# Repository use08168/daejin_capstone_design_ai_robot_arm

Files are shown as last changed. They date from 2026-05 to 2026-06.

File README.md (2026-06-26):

# 🦾 AI 기반 6-DOF 음성 제어 로봇팔

> **Voice-Controlled Autonomous Grasping Manipulator**
> 대진대학교 캡스톤 디자인 — 한국어 음성 명령으로 객체를 인식하고 안전하게 그립하는 분산 AI 추론 기반 6-DOF 로봇팔.

<p align="center">
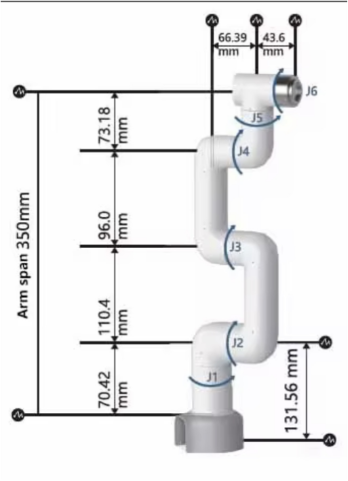
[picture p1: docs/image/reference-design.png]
6-DOF 로봇팔 설계 (J1~J6, arm span 350mm)
  
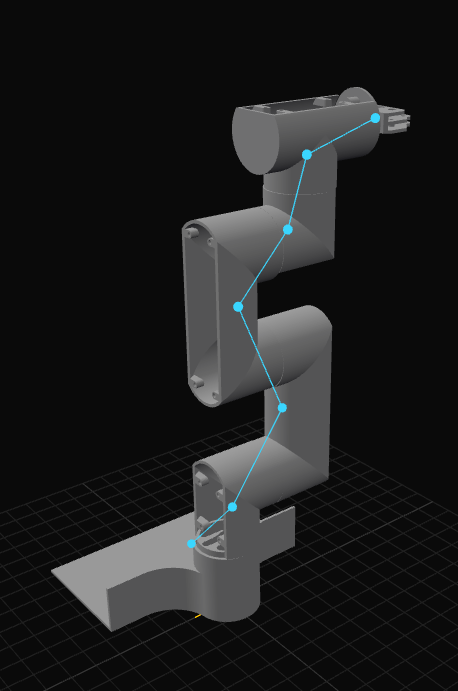
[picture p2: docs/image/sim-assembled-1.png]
STL로 조립한 3D 디지털 트윈 (6관절 리깅)
  
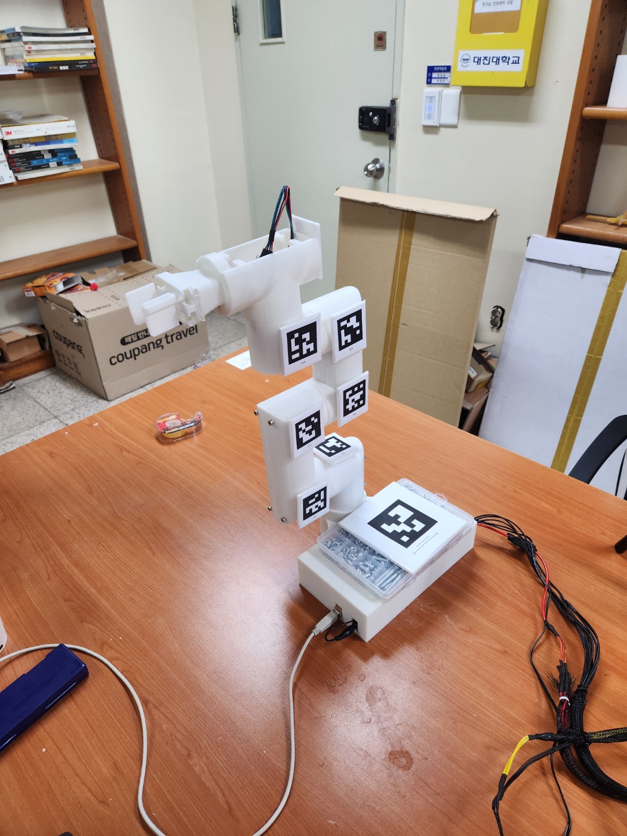
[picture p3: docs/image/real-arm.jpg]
실물 6-DOF 로봇팔 (각 링크에 ArUco 마커 부착)
  
</p>
<p align="center"><sub>참조 설계(좌) → 실측 STL로 만든 3D 디지털 트윈(중) → 실물 6-DOF 로봇팔(우, 각 링크에 ArUco 마커). 시뮬레이션으로 동작을 미리 보고 실물과 연동 구동.</sub></p>

```
사용자: "빨간 컵을 책 옆에 놔줘"
   ↓
음성 인식 → 객체 인식 → 의도 파악 → 동작 계획 →
IK 계산 → 안전 검증 → 모터 제어 → 그립 → 이동 → 놓기
```

---

## 🎬 데모 영상

> Google Drive(뷰어 공개) 링크. 각 항목은 해당 기술 문서에도 연결돼 있다.

| 데모 | 영상 |
|---|---|
| **3D 시뮬레이터 동작** (조립·리깅·제어) | [▶ 보기](https://drive.google.com/file/d/1hU2PR68-Gy2XqOHGjDWO9H2JxIDRQaFw/view?usp=sharing) |
| **잡기·놓기 런타임** (AI 파지 → 들기 → 놓기) | [▶ ①](https://drive.google.com/file/d/1SrEo43e4rWohGsKSrXign7xtEpKEwyvU/view?usp=sharing) · [②](https://drive.google.com/file/d/1nPFacq3uxQnlIRRXGvIO_LedIHU8A4sO/view?usp=sharing) · [③](https://drive.google.com/file/d/1vkNTbvnbb-N0b4rIz5xn-92pryiSB7c0/view?usp=sharing) |
| **파지 데이터셋 생성** (FK 샘플링) | [▶ ①](https://drive.google.com/file/d/1aMuK7l9k4ZoUPRI2btJ8vOeubB9G_r45/view?usp=sharing) · [②](https://drive.google.com/file/d/18LRvhoQJ6_2y2a_KH3mV3oGGfNr9pnhw/view?usp=sharing) |
| **MLP 파지 학습** | [▶ 보기](https://drive.google.com/file/d/1riFp9NCgwCPHXfsDhdb2TVaCAP688P8R/view?usp=sharing) |
| **디지털트윈 C-space 안전 검증** | [▶ ①](https://drive.google.com/file/d/1vYuo53dGs2aWkysy1HClAFdfzunhA5IU/view?usp=sharing) · [②](https://drive.google.com/file/d/1E0i8ZytOhljyalwJxXthOAcU_MwYzIW0/view?usp=sharing) |
| **로봇팔 3D 인식 과정** (스테레오 삼각측량) | [▶ 보기](https://drive.google.com/file/d/1MBFXagUDMlq_0g1TG0gAltHQs-gzVrMP/view?usp=sharing) |
| **ChArUco 촬영** (캘리브레이션 셋업) | [▶ ①](https://drive.google.com/file/d/1Vn4H3W7XyQx7gDIsGqlCTaZhZLj_LL9r/view?usp=sharing) · [②](https://drive.google.com/file/d/1bMQTdBhah7Y777o8GNDhDxKxGlNs9XDX/view?usp=sharing) |

---

## 시스템 구조

3계층 분산 아키텍처. 의미 추론은 위로, 결정적·실시간 작업은 아래로.

| 계층 | 장치 | 역할 | 주요 기술 |
|---|---|---|---|
| **Layer 3** | MSI EdgeXpert | "무엇을 할지" 결정 | Whisper · Gemma 4 · Qwen3 · FAISS |
| **Layer 2** | 노트북 | "어떻게 할지" 번역 | Django · YOLO-World · OpenCV · Pieper IK · 안전 감시 |
| **Layer 1** | Arduino Mega 2560 | "실제 실행" | PCA9685 · VL53L0X ToF |

```
AI 서버  ──gRPC/Protobuf──  노트북  ──USB Serial(CRC-16)──  Arduino
```

---

## 정량 목표

| 항목 | 목표 |  | 항목 | 목표 |
|---|---|--|---|---|
| 그립 정밀도 | ±2mm | | 비상 정지 응답 | <100ms |
| 명령→그립 완료 | <10초 | | 페이로드 | 150g |
| 객체 인식 정확도 | ≥95% | | 자유도 / 제어주기 | 6-DOF / 50Hz |

---

## 🛠️ 기술 스택

### 💻 핵심 개발 및 AI/ML 스택

| 카테고리 | 기술 스택 |
|---|---|
| **사용 언어** |   |
| **음성 인식 (STT)** |  |
| **LLM / VLM** |  |
| **객체 탐지** |  |
| **벡터 데이터베이스** |  |
| **임베딩 모델** |  |
| **학습 / 추론 프레임워크** |   |
| **비전 / 수치 연산** |    |

### 🤖 제어 · 통신 · 하드웨어

| 카테고리 | 기술 스택 |
|---|---|
| **노트북 웹/제어 계층** |  |
| **MCU / 펌웨어** |   |
| **모터 제어** |  |
| **센서** |  |
| **통신** |     |
| **비동기 제어 (예정: 실시간 제어 루프)** |  |
| **AI 서버 / GPU** |   |

### 🤝 협업 및 기타

| 카테고리 | 기술 스택 |
|---|---|
| **형상 관리 / 협업** |     |
| **테스트** |  |
| **개발 환경** |  |

---

## 저장소 구조

**바깥은 개요, 안으로 갈수록 상세** — 폴더로 들어갈수록 구체적인 문서가 나온다.

```
daejin_capstone_design_ai_robot_arm/
├── README.md        # ← 지금 이 문서: 목적·기술스택·기능·현황 (쇼케이스)
├── docs/            # 공통: 아키텍처 + 왜 이렇게 나눴는지 + 인터페이스 명세
├── ai_server/       # L3 AI 추론 서버   README + docs/  (무엇을 할지)
├── laptop/          # L2 제어 허브       README + docs/  (어떻게 할지)
└── arduino/         # L1 펌웨어          README + docs/  (실제 실행)
```

- 각 컴포넌트 **폴더 루트 `README.md`** = 그 폴더의 개요(역할·하위 폴더 지도).
- 각 컴포넌트 **`docs/`** = 기능 명세(가장 상세).
- 루트 **`docs/`** = 계층이 공통으로 합의하는 명세.

---

## 문서 안내

| 더 알고 싶다면 | 문서 |
|---|---|
| **전체 아키텍처 · 왜 3계층인지** | [docs/README.md](docs/README.md) · [docs/1_architecture.md](docs/1_architecture.md) |
| 계층 간 인터페이스 | [grpc_interface](docs/3_grpc_interface.md) · [serial_protocol](docs/4_serial_protocol.md) · [dsl_spec](docs/5_dsl_spec.md) · [conventions](docs/6_conventions.md) · [system_spec](docs/2_system_spec.md) |
| **노트북 — 비전·3D 시뮬·실물 연동** | [laptop/README.md](laptop/README.md) → [laptop/docs](laptop/docs/README.md) |
| **3D 모델링·조립·연동** (방법 포함) | [laptop/docs/8_arm3d_simulator.md](laptop/docs/8_arm3d_simulator.md) |
| **ChArUco 캘리브레이션** (방법 포함) | [laptop/docs/3_coordinate_3d_pipeline.md](laptop/docs/3_coordinate_3d_pipeline.md) |
| 펌웨어 · 서보 캘리브레이션 | [arduino/README.md](arduino/README.md) → [arduino/docs](arduino/docs/README.md) |
| AI 서버 (예정) | [ai_server/README.md](ai_server/README.md) |

---

## 학술적 차별화

1. **Code-as-Policies** — LLM이 제한된 DSL을 직접 생성 (RT-2 / ProgPrompt 계열)
2. **Visual-Kinematic Self-Calibration** — 로봇이 자기 자신을 측정해 운동학 보정 (±15mm → ±2mm)
3. **RAG-Grounded** — FAISS + Qwen3 임베딩으로 LLM 환각 차단
4. **카메라 기반 Defense-in-Depth Safety** — 4계층 독립 검증

---

## 현재 상태

📌 **하드웨어 조립 완료 · 비전·시뮬레이션·실물 연동까지 구동 — AI 연동 직전 단계.**

- 6-DOF 로봇팔 **조립 완료**. Arduino + PCA9685로 J1~J6 서보 **펄스 캘리브레이션 완료** (관절별 0°/180° 실측, [arduino/docs/1_servo_calibration.md](arduino/docs/1_servo_calibration.md)).
- **비전 (실측 검증):** YOLO-World 객체 탐지(GPU) + **ChArUco 스테레오 캘리브레이션**(`DICT_5X5_100`, 6×8, 30/23mm, 재투영오차 ~0.5px, 베이스라인 588mm) + 삼각측량 3D 좌표(보드 30mm를 0.32mm 오차로 복원). → [laptop/docs/3_coordinate_3d_pipeline.md](laptop/docs/3_coordinate_3d_pipeline.md)
- **STL 3D 시뮬레이터 + 실물 연동 (4페이지, Three.js):** 팀원 STL 부품을 브라우저에서 **면대면 결합(CATIA식 원통 동심 + 평면 일치)** 으로 직접 조립 → **6관절 리깅 완료**. 관절 슬라이더가 3D를 돌리고, **연동 ON 시 실제 서보를 동시 구동**(각도→펄스 변환은 노트북, 아두이노엔 `u ch us` 전송 — 펌웨어 수정 불필요). → [laptop/docs/8_arm3d_simulator.md](laptop/docs/8_arm3d_simulator.md)
- **웹 UI 4페이지**(Django): 카메라·탐지(좌/우 카메라 선택) / 캘리브레이션 위저드 / 자연어 제어(골격) / **STL 3D 시뮬레이터·실물 연동**. → [laptop/docs/1_web_app.md](laptop/docs/1_web_app.md)
- **이후 단계:** 베이스 ArUco로 카메라→로봇 좌표변환(T), EdgeXpert / AI 서버(Whisper·Gemma) 연동 → 자연어 명령이 위 연동 경로로 로봇 구동. **미통합:** ToF(VL53L0X), 이진 시리얼 프로토콜.

---

> 대진대학교 캡스톤 디자인 프로젝트

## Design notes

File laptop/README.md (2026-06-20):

# laptop/ — 제어 허브 (Control Hub)

> **3계층 중 Layer 2 — "어떻게 할지"를 번역하는 노트북.**
> 위(AI 서버)의 의미 명령을 받아 **비전·좌표·운동학**을 계산하고, 아래(Arduino)가 실행할 **모터 명령**으로 바꾼다.
> 동시에 로봇 **STL 부품으로 3D 디지털 트윈**을 만들어 시뮬레이션하고 실물과 연동한다.

전체 구조에서 이 폴더의 위치 → [공통 docs/1_architecture.md](../docs/1_architecture.md)

---

## 이 폴더가 하는 일

| 기능 | 상태 | 핵심 |
|---|:----:|---|
| 스테레오 **객체 탐지** | ✅ | YOLO-World(GPU, 오픈 보캐뷸러리) |
| **3D 좌표 복원** | ✅ | ChArUco 스테레오 캘리브레이션 + 삼각측량 (보드 30mm를 0.32mm 오차로 복원) |
| **3D 시뮬레이터 + 실물 연동** | ✅ | STL 면대면 조립 → 6관절 리깅 → 슬라이더가 3D+실물 서보 동시 구동 |
| 카메라→로봇 변환, IK, 안전, AI 연동 | ⬜ | 이후 단계 |

브라우저 UI는 Django 웹앱(4페이지). 자세한 동작은 [docs/1_web_app.md](docs/1_web_app.md).

---

## 폴더 구조

| 경로 | 역할 |
|---|---|
| `armvision/` | Django 앱 — 카메라·탐지·캘리브레이션·3D 시뮬·시리얼 브리지 + 템플릿(페이지) |
| `calibration/` | 캘리브레이션·검증 스크립트 + 인쇄용 타깃(ChArUco/ArUco) 생성기 |
| `cad/` | 로봇 STL 부품 18개 + 조립 결과 `assembly.json` |
| `config/` | Django 프로젝트 설정 |
| `docs/` | **기능 명세 (이 폴더의 상세 문서)** ↓ |
| `manage.py`, `requirements.txt`, `weights/` | 실행 진입점 · 의존성 · 모델 가중치(gitignore) |

### armvision/ 주요 모듈
`camera.py`(카메라 스레드·좌/우 선택) · `detector.py`(YOLO-World) · `charuco.py`(ChArUco) ·
`stereo3d.py`(삼각측량) · `arduino_bridge.py`(시리얼) · `views.py`/`urls.py`/`templates/`(페이지·API)

---

## 빠른 시작

```bash
pip install -r requirements.txt        # django, ultralytics, opencv-contrib, pyserial, pygrabber, torch …
python manage.py runserver             # http://127.0.0.1:8000/  (실물 연동 시 --noreload 권장)
```
> GPU(torch+CUDA)는 환경에 맞는 휠로 설치. 모델 가중치 `yolov8m-worldv2.pt`는 최초 실행 시 자동 다운로드.

---

## 더 자세히 → [docs/](docs/README.md)

| 문서 | 내용 |
|---|---|
| [docs/README.md](docs/README.md) | **기능 명세 허브** (계층 책임·코드 구조) |
| [1_web_app.md](docs/1_web_app.md) | 4페이지 웹 UI + 엔드포인트 |
| [8_arm3d_simulator.md](docs/8_arm3d_simulator.md) | **STL 3D 시뮬레이터 + 실물 연동** (모델링·조립·제어) |
| [3_coordinate_3d_pipeline.md](docs/3_coordinate_3d_pipeline.md) | ChArUco 캘리브레이션 + 삼각측량 3D |
| [2_object_detection_model.md](docs/2_object_detection_model.md) | YOLO-World 선정 근거 |
| [15_aruco_markers.md](docs/15_aruco_markers.md) | 로봇 마커 스킴 |
| [14_setup_procedure.md](docs/14_setup_procedure.md) | 초기 셋업 6단계 절차 |

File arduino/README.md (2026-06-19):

# arduino/ — 펌웨어 (Hardware Executor)

> **3계층 중 Layer 1 — "실제 실행".**
> 노트북이 보낸 명령을 받아 PWM을 생성해 서보를 구동하고, 센서값을 보고한다.
> **판단·계산은 하지 않는다** (의미 추론=AI 서버, 결정적 계산=노트북).

전체 구조에서 이 폴더의 위치 → [공통 docs/1_architecture.md](../docs/1_architecture.md)

---

## 이 폴더가 하는 일

- 노트북 명령 수신 → **PCA9685로 PWM 생성** → 서보(J1~J6 + 그리퍼) 구동
- **VL53L0X ToF**로 거리 측정(그립 정밀 제어용, 입고 후)
- 센서·상태 보고, 비상 동결

PlatformIO 프로젝트(Arduino Mega 2560). 보드/포트/통신·PWM 매핑 등 상세 → **[docs/README.md](docs/README.md)**.

---

## 현재 상태

- 하드웨어 1차 검증 완료. **서보 J1~J6 펄스 캘리브레이션 완료** → [docs/1_servo_calibration.md](docs/1_servo_calibration.md).
- 현재 펌웨어는 사람이 읽는 **ASCII 시리얼 명령**(`u <ch> <us>` 펄스 직접 등)으로 동작 → 노트북 4페이지 연동이 이 명령을 그대로 사용(펌웨어 무수정).
- **목표(예정):** 이진 CommandPacket + CRC-16 프로토콜([../docs/4_serial_protocol.md](../docs/4_serial_protocol.md)).

---

## 더 자세히 → [docs/](docs/README.md)

| 문서 | 내용 |
|---|---|
| [docs/README.md](docs/README.md) | 펌웨어 기능 명세 (하드웨어·PWM 매핑·업로드 절차) |
| [docs/1_servo_calibration.md](docs/1_servo_calibration.md) | 관절별 0°/180° 펄스 실측값 |

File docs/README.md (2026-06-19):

# docs/ — 공통 명세 & 아키텍처

> 루트 [README](../README.md)가 **"무엇을·왜"** 라면, 이 폴더는 그것을 **구체화** 한다 —
> 전체 아키텍처, 세 컴포넌트가 **왜 이렇게 나뉘는지**, 그리고 계층이 **공통으로 합의해야 하는 인터페이스 명세**.
> 한 컴포넌트 내부의 기능 명세는 각 폴더의 `docs/`에 둔다(아래 "더 깊이" 참조).

---

## 왜 3개의 폴더로 나눴나 (구조 근거)

이 프로젝트는 **3계층 분산 구조**다. 핵심 원칙: **의미 추론은 위로, 결정적·실시간 작업은 아래로.**

| 폴더 | 계층 | 존재 이유 | 핵심 |
|---|---|---|---|
| [`ai_server/`](../ai_server/README.md) | L3 | **"무엇을 할지"** — 음성·자연어·이미지를 이해해 의도(DSL)를 만든다. 무거운 LLM/VLM은 GPU 서버(EdgeXpert)에 둔다. | Whisper · Gemma · Qwen3 · FAISS |
| [`laptop/`](../laptop/README.md) | L2 | **"어떻게 할지"** — 의도를 비전·좌표·운동학으로 번역하고, **실시간 안전을 AI 응답에 의존하지 않고 독립 보장**한다. | YOLO-World · OpenCV · IK · Three.js 3D |
| [`arduino/`](../arduino/README.md) | L1 | **"실제 실행"** — 결정적 50Hz PWM 생성. 판단하지 않는 단순 실행자라 펌웨어가 작고 안정적. | PCA9685 · VL53L0X |

> 이렇게 나누면 ① 네트워크가 끊겨도 노트북이 **독립적으로 비상 정지**할 수 있고, ② 무거운 추론(서버)과 실시간 제어(MCU)를 분리해 각자 최적화할 수 있다. 상세 → [1_architecture.md](1_architecture.md).

```
사용자 음성 ─▶ [AI 서버] 의도(DSL) ──gRPC──▶ [노트북] 좌표·IK·안전 ──Serial──▶ [Arduino] PWM ─▶ 서보
```

---

## 공통 인터페이스 명세 (계층이 합의)

| 문서 | 내용 |
|---|---|
| [1_architecture.md](1_architecture.md) | 3계층 구조·책임 분리·통신 채널·동작 시나리오·정량 목표 |
| [2_system_spec.md](2_system_spec.md) | 시스템 마스터 사양 (전체 레퍼런스) |
| [3_grpc_interface.md](3_grpc_interface.md) | AI 서버 ↔ 노트북 gRPC/Protobuf |
| [4_serial_protocol.md](4_serial_protocol.md) | 노트북 ↔ Arduino USB Serial 패킷 |
| [5_dsl_spec.md](5_dsl_spec.md) | JSON DSL (명령 표현 언어) + 검증 |
| [6_conventions.md](6_conventions.md) | 좌표계 / 단위 / 명명 규약 |

**원칙:** 인터페이스는 **코드보다 문서를 먼저** 갱신한다. 양측 코드가 같은 문서에서 파생되므로 문서 불일치 = 통신 장애.

---

## 더 깊이 — 컴포넌트별 상세 (안으로 갈수록 구체적)

```
README.md (루트)        프로젝트 목적·기술스택·기능·현황
  └ docs/               ← 여기: 아키텍처 + 공통 인터페이스
      └ <컴포넌트>/README.md   컴포넌트 개요 + 하위 폴더 지도
          └ <컴포넌트>/docs/   기능 명세 (가장 상세)
```

- [laptop/docs](../laptop/docs/README.md) — 비전·3D 시뮬레이터·실물 연동 (기능 명세)
- [arduino/docs](../arduino/docs/README.md) — 펌웨어 (PWM·서보 캘리브레이션)
- [ai_server/docs](../ai_server/docs/README.md) — AI 추론 서버

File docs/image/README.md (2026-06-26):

# docs/image — 문서용 사진

문서에서 참조하는 사진/캡처/GIF를 모은 곳. (GIF는 GitHub에서 자동 재생 — 데모용)

## 현재 보유 (문서에 연결됨)

| 파일 | 내용 | 연결된 문서 |
|---|---|---|
| `reference-design.png` ✅ | 참조 설계도 (J1~J6, 링크 치수, arm span 350mm) | 루트 README, arm3d_simulator |
| `sim-assembled-1.png` ✅ | 3D 6관절 조립 완료 (시안 고정선) — 대표컷 | 루트 README, arm3d_simulator |
| `sim-assembled-2.png` ✅ | 〃 다른 각도 | arm3d_simulator |
| `sim-face-mate.png` ✅ | 결합: 원통(주황/초록) 선택 | arm3d_simulator |
| `sim-control.png` ✅ | 제어 모드 전체 UI (관절 슬라이더+연동) | arm3d_simulator |
| `webapp-detect.png` ✅ | 1페이지 YOLO 탐지 + 2D/3D 좌표표 | web_app |
| `calib-result.png` ✅ | 2페이지 ChArUco 코너 검출(양 카메라) | coordinate_3d_pipeline |
| `hardware-wiring.png` ✅ | Mega+PCA9685+ToF+서보+전원 배선도 | arduino/docs |
| `real-arm.jpg` ✅ | **실물 6-DOF 로봇팔**(링크별 ArUco 마커) | 루트 README, arm3d_simulator, aruco_markers |
| `charuco-board.png` ✅ | 인쇄용 ChArUco 보드(DICT_5X5_100, 6×8) | coordinate_3d_pipeline, setup_procedure |
| `stereo-rig.png` ✅ | 좌·우 카메라가 본 로봇팔(스테레오 셋업) | setup_procedure |
| `aruco-detect.png` ✅ | ArUco 포즈 검출(위치 mm·회전 deg) | aruco_markers |
| `setup-transform.png` ✅ | 2페이지 4~6단계(베이스·변환 T·마커 측정) | setup_procedure |
| `vlm-chat.png` ✅ | 자연어 제어 VLM 장면 이해 채팅 | ai_integration |
| `jaw-box.png` ✅ | 그리퍼 TCP·jaw 박스·접근축 정의 | grasp_ik_method |
| `joint-sweep.png` ✅ | 관절 스윕 마커 분포(콜드스타트) | coldstart_procedure |
| `grasp-sim.gif` 🎞️ | 4페이지 AI 파지 시뮬(잡기·들기·놓기) | grasp_place_runtime |
| `mlp-training.gif` 🎞️ | 5페이지 MLP 학습 과정(손실·정확도) | grasp_learning_mlp |

## 아직 없음 (있으면 더 좋음)

| 파일명 | 내용 | 쓰일 곳 |
|---|---|---|
| `sim-control-real.jpg` | 실물+3D 동시 자세 한 컷(연동 데모) | arm3d_simulator |

---

> 새 사진을 넣은 뒤 알려주면 해당 문서에 `![설명](../../docs/image/파일명)`(루트 README는 `docs/image/파일명`)으로 연결한다.
> 권장: 가로 1200~1600px, JPG(사진)/PNG(UI 캡처), 한 장 ~1MB 이하.

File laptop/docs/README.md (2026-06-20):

# 노트북 (Control Hub) — 기능 명세

> 📂 [루트](../../README.md) → [공통 docs](../../docs/README.md) → [laptop](../README.md) → **laptop/docs (여기, 가장 상세)**

> **역할: "어떻게 할지" 번역.** AI 서버의 DSL을 실제 모터 명령으로 변환하고, 실시간 안전을 독립적으로 보장한다.
> 위로는 [gRPC](../../docs/3_grpc_interface.md)로 AI 서버와, 아래로는 [Serial](../../docs/4_serial_protocol.md)로 Arduino와 통신한다.

### 세부 문서

| 문서 | 내용 |
|---|---|
| [1_web_app.md](1_web_app.md) | Django 웹앱 4페이지 + 엔드포인트 기능 명세 |
| [2_object_detection_model.md](2_object_detection_model.md) | 객체 탐지 모델 선정 (YOLO-World, 오픈 보캐뷸러리) |
| [3_coordinate_3d_pipeline.md](3_coordinate_3d_pipeline.md) | ChArUco 스테레오 캘리브레이션 + 삼각측량 3D 파이프라인 |
| [4_measurement_validation.md](4_measurement_validation.md) | **측정 검증** — 마커 3D가 실제 강체 운동학과 일치(불변점·강체거리·축복원) |
| [5_coldstart_procedure.md](5_coldstart_procedure.md) | **콜드스타트 절차** — 비전-운동학 자가보정(축복원·PoE FK·sim-real gap·계층 역할) |
| [6_digital_twin_safety.md](6_digital_twin_safety.md) | **디지털 트윈 안전 + 자가학습** — C-space 충돌지도·충돌예측 신경망·능동학습·AI 검증층 |
| [7_ai_integration.md](7_ai_integration.md) | **AI 서버 연동(3페이지)** — gRPC 클라이언트·자연어/음성 제어·3D 미러·set_joint 실물 실행 |
| [8_arm3d_simulator.md](8_arm3d_simulator.md) | **STL 3D 시뮬레이터 + 실물 연동(4페이지)** — 조립·면결합·관절제어 |
| [9_grasp_pipeline.md](9_grasp_pipeline.md) | **물체 파지 파이프라인** — TCP 정의·축보정·파지DB·6DOF IK·방향별 도달영역(capability map) |
| [10_grasp_ik_method.md](10_grasp_ik_method.md) | **데이터 기반 파지 IK — 방법론 도출 과정과 최종 정식화**(학술) — 비용함수 진화(v1→v4)·경로·capability 정식화 |
| [11_gripper_design.md](11_gripper_design.md) | **그리퍼 정밀 설계** — 평행집게 개폐(prismatic) 시뮬·왜 디테일하게(파지 접촉검증)·J7 제어·리깅 드리프트 제거 |
| [12_grasp_orientation_learning.md](12_grasp_orientation_learning.md) | **파지 방향 문제와 접근 조건부 학습** — 형상·바닥에 따른 수직/수평 결정·접근 타입별 데이터·접근 선택 학습 |
| [13_grasp_learning_mlp.md](13_grasp_learning_mlp.md) | **파지 학습 MLP** — 참고 토대·입력 데이터·학습 원리·결과값(분류 92.7%·접근선택 86.8%)·용도·손목(J6)roll 최적화·**참고문헌**(6-DOF 파지 생성) |
| [14_setup_procedure.md](14_setup_procedure.md) | 환경 구성 / 실행 절차 |
| [15_aruco_markers.md](15_aruco_markers.md) | ArUco / ChArUco 마커 명세 |
| [16_grasp_place_runtime.md](16_grasp_place_runtime.md) | **파지·놓기 실행 런타임** — 두 단계 집기(standoff→직선)·충돌인식·AI 파지·최적자세·접근맵/구조한계·**놓기 프로세스**·**J6 자이로 수평유지** |
| [17_design_journey.md](17_design_journey.md) | **설계 여정(고민 기록)** — 학습 방식 선택·데이터 신뢰성 싸움·학습 한계 vs 구조 한계·두 단계 접근·놓기/자이로 결정 로그 |

> **현황:** ① YOLO-World 탐지 + 객체 id, ② ChArUco 스테레오 캘리브레이션(~0.5px, 588mm) + 삼각측량 3D(30mm를 0.32mm 오차로 복원) — 실측 검증. ③ STL 3D 시뮬레이터로 6관절 조립·리깅 완료 → 관절 슬라이더가 3D+실물 서보 동시 구동(연동 ON/OFF). ④ 디지털 트윈 안전검증(C-space 충돌지도·신경망 99.5%·능동학습)·콜드스타트 자가보정. ⑤ **파지 파이프라인**(FK 샘플링 파지 DB 100만·6DOF IK·capability map) + **그리퍼 정밀 개폐**(평행집게 슬라이드·J7 제어). ⑥ **파지 학습 MLP**(접근 조건부·충돌인식 데이터) + **집기/놓기 실행 런타임**(두 단계 집기·자이로 놓기). **다음: AI 서버(Gemma) 연동 — pick/place DSL.**

---

## 1. 하드웨어 / 환경

| 항목 | 값 |
|---|-----|
| CPU | Intel i7-12700H |
| GPU | RTX 3050 (4GB VRAM) |
| RAM | 16GB DDR4 |
| 언어 | Python 3.12 |
| 웹/제어 계층 | Django (project=`config`, app=`armvision`) |
| 역할 | 제어 + 비전 처리 |

---

## 2. 기능 책임

| 영역 | 책임 |
|---|---|
| 비전 | YOLO-World 객체 탐지(실시간, GPU), 삼각측량, ChArUco/ArUco 인식, 좌표 변환 |
| 운동학 | Pieper IK, 순기구학, S-curve 보간, 특이점 회피, PWM 매핑 |
| DSL | AI 서버 DSL 4단계 검증 + op 핸들러 실행 |
| 안전 | 카메라 기반 4계층 비상 정지 (AI 서버 비의존) |
| 그립 | PCA 기반 그립 자세 결정, ToF 폐루프 정밀 하강 |
| 캘리브레이션 | 콜드스타트 visual-kinematic, DH LM 최적화 |
| 통신 | gRPC 클라이언트(AI 서버), Serial 브릿지(Arduino) |

---

## 3. 4단계 변환 사슬 (핵심)

```
DSL + 픽셀좌표 → ①삼각측량 → ②좌표변환 → ③IK(Pieper) → ④S-curve+PWM → Arduino(50Hz)
```
수식 세부는 [2_system_spec.md §3](../../docs/2_system_spec.md) 참조.

---

## 4. 안전 (독립 보장)

- **메커니즘 A (ToF 폐루프):** 그립 정밀 제어 전용, 비상 정지 아님.
- **메커니즘 B (카메라 4계층):** 사람 침입 / 객체 급격 이동 / 경로 장애물 / 타겟 소실.
- 비상 정지는 AI 서버 응답에 의존하지 않으며, 응답 예산 <100ms.
- AI 서버 heartbeat 3초 무응답 시 독립적으로 비상 정지.

---

## 5. 코드 구조 (현행 — Django 웹앱)

노트북 계층은 **Django 웹앱**으로 구현되어 있다. 4개 페이지를 제공한다:
(1) 카메라·객체탐지(좌/우 카메라 선택), (2) 캘리브레이션 위저드(6단계), (3) 자연어 제어(골격),
(4) **STL 3D 시뮬레이터 + 실물 연동**(조립·면결합·관절 슬라이더→3D+실물). 상세는 [1_web_app.md](1_web_app.md), [8_arm3d_simulator.md](8_arm3d_simulator.md).

```
laptop/
├── manage.py
├── config/                  # Django 프로젝트
├── armvision/               # 메인 앱
│   ├── camera.py            # 카메라 캡처(자가치유) + 좌/우 선택(cam_config.json)
│   ├── detector.py          # YOLO-World 객체 탐지
│   ├── charuco.py           # ChArUco 캘리브레이션
│   ├── stereo3d.py          # 스테레오 삼각측량 3D
│   ├── arduino_bridge.py    # 실물 로봇팔 시리얼(pyserial, COM9)
│   ├── views.py
│   └── templates/           # arm3d.html = 3D 시뮬레이터(조립/결합/제어)
├── cad/                     # 팀원 STL 부품 + assembly.json(조립 저장)
├── calibration/
│   ├── calibrate_stereo.py
│   ├── validate_triangulation.py
│   ├── make_targets.py
│   └── make_arm_markers.py
└── docs/
```

> **참고(예정):** 실시간 제어 루프(camera/safety/arduino/command 병행 실행)는 향후 asyncio 기반으로 구현 예정이다. 현재 웹/제어 계층은 Django다.

---

## 6. 주요 의존성 (예정)

`django`, `ultralytics`(YOLO-World `yolov8m-worldv2`), `grpcio`, `pyserial`, `opencv-python`, `opencv-contrib-python`(ChArUco/ArUco), `numpy`, `scipy`, `torch`, `torchvision`.

---

## 7. 단독 검증 항목 (현 보유 하드웨어로 가능)

- [x] 카메라 2대 캡처 + YOLO-World 실시간 객체 탐지 구동 확인 (GPU, RTX 3050)
- [x] ChArUco 스테레오 캘리브레이션 (재투영오차 ~0.5px, 베이스라인 588mm)
- [x] 삼각측량 정확도 검증 (보드 30mm를 0.32mm 오차로 복원)
- [x] STL 3D 시뮬레이터로 6관절 조립·리깅 + 관절 슬라이더 구동
- [x] Arduino Serial 펄스 전송(`arduino_bridge.py` → `u ch us`) + 4페이지 연동 토글
- [ ] IK/FK 순수 Python 단위 테스트 (로봇 없이)
- [ ] (ToF 센서 입고 후) VL53L0X 측정 + 이진 패킷 프로토콜

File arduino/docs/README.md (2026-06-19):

# Arduino Mega 2560 (펌웨어) — 기능 명세

> **역할: "실제 실행".** 노트북의 명령을 받아 PWM을 생성하고, 센서값을 보고한다.
> 판단·계산은 하지 않는다 (의미 추론=AI 서버, 결정적 계산=노트북).
> 통신 명세: [Serial 프로토콜](../../docs/4_serial_protocol.md)

---

## 1. 하드웨어 / 환경

| 항목 | 값 |
|---|-----|
| 보드 | Arduino Mega 2560 |
| 프레임워크 | PlatformIO + Arduino |
| 언어 | C++ |
| PWM 드라이버 | PCA9685 (16ch, I2C, 12bit, addr 0x40) |
| ToF 센서 | VL53L0X (I2C, addr 0x29) |
| Baudrate | 115200 |

### 액추에이터

| 관절 | 서보 | 토크(kg·cm) |
|---|---|---|
| J1 base / J2 shoulder | DS3235 Pro | 35 |
| J3 elbow / J4 pitch | DS3218 Pro | 20 |
| J5 roll / J6 gripper_rot / gripper | MG90S | 2.2 |

**전원 주의:** 서보 전원은 SMPS(Meanwell LRS-150-5, 5V 150W)에서 직접 공급한다.
**PCA9685 PCB 트레이스로 서보 전류를 통과시키지 않는다** (트레이스 한계 3~5A vs 잠재 부하 16.5A).

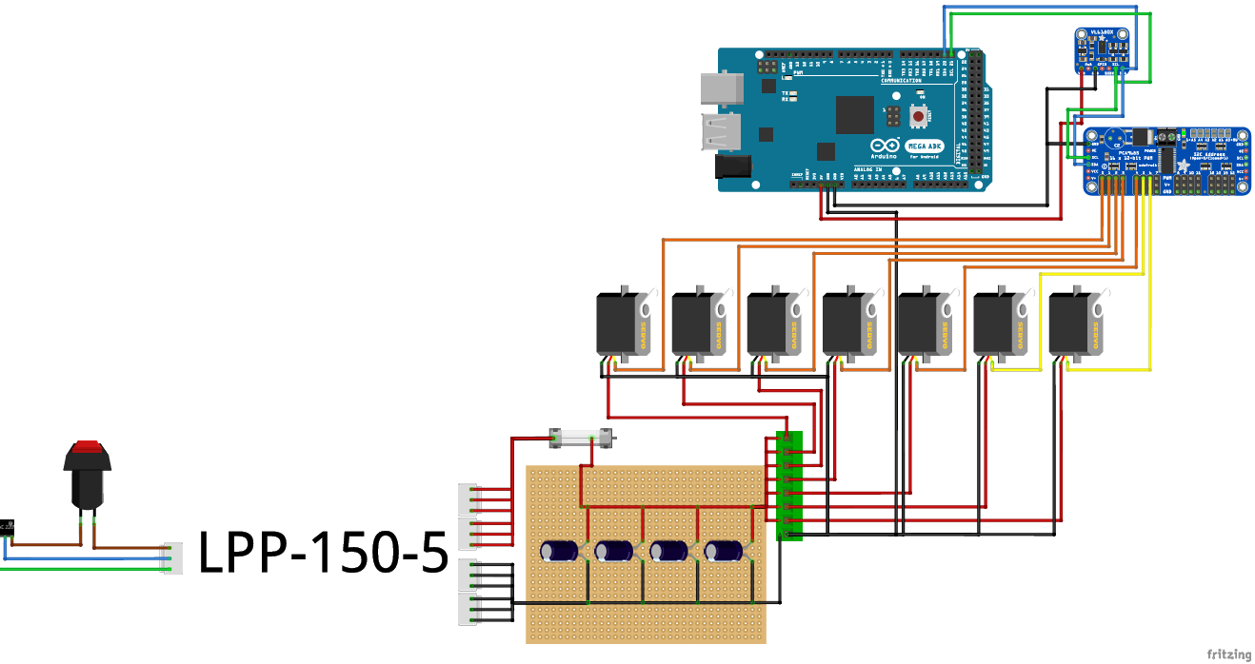
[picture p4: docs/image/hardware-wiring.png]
배선도 — Arduino Mega + PCA9685 + VL53L0X + 서보 7개 + SMPS 전원분배(콘덴서)·비상정지


> 위 배선도: 서보 전원은 SMPS에서 전원분배 보드(대용량 콘덴서로 순간 전류 완충)를 거쳐 공급, I2C(SDA/SCL)는 PCA9685·VL53L0X가 공유. 신호선만 PCA9685로 들어간다.

---

## 2. 기능 책임

1. **명령 수신** — 노트북 Command Packet 수신, CRC 검증.
2. **PWM 생성** — 관절 각도 → PCA9685 12bit 값 → 서보 구동.
3. **그리퍼 제어** — open/close.
4. **ToF 측정** — VL53L0X로 거리(mm) 측정 (High Accuracy mode).
5. **센서 보고** — Sensor Packet으로 ToF·현재 각도·그리퍼·비상버튼 상태를 10Hz 송신.
6. **비상 동결** — emergency 명령 수신 시 현재 PWM 동결 (0으로 만들지 않음).

---

## 3. 메인 루프 개요

```
loop():
  1. Serial에 패킷 도착 시 → CRC 검증 → command_type 분기
       0x01 joint    → setJointAngles()
       0x02 gripper  → setGripper()
       0x03 emergency→ freeze()
     → sendAck()
  2. 10Hz마다 SensorPacket 송신 (ToF + 현재 각도 + 비상버튼)
```

> **현황(2026-06):** 위 이진 CommandPacket 구조는 **최종 목표**다. 현재 캘리브레이션·검증에 쓰는
> 테스트 펌웨어(`src/main.cpp`)는 사람이 읽기 쉬운 **ASCII 시리얼 명령**(`u <ch> <us>` 펄스 직접,
> `a <ch> <deg>`, `s`/`w` 스윕 등)으로 동작하며, 노트북에서 펄스를 보내 서보를 구동한다. 추후 이진
> 패킷 프로토콜로 교체 예정. (각도→펄스 변환은 노트북이 담당 → [1_servo_calibration.md](1_servo_calibration.md))

---

## 4. PWM 매핑

```
PWM_μs    = 1500 + (θ_deg / 90) * 500
PCA_value = int(PWM_μs * 4096 / 20000)
```
> **주의:** 위 균일 공식은 원래 설계값이다. 실제 매핑은 관절별 실측 0°/180° 펄스폭([1_servo_calibration.md](1_servo_calibration.md))을 사용하며 가동범위는 **0~180°**다. 서보가 **끝 스톱 없는 마그네틱(절대위치) 엔코더형**이라 소프트웨어 관절 한계가 필수다.

규약 세부는 [6_conventions.md](../../docs/6_conventions.md) 참조.

---

## 5. 예정 코드 구조 (구현 단계)

```
arduino/
├── platformio.ini
├── include/
│   ├── packet_protocol.h    # 노트북 packet_codec.py 와 동기
│   └── pin_config.h
├── src/
│   ├── main.cpp
│   ├── servo_control.cpp    # PCA9685 + 서보
│   ├── tof_sensor.cpp       # VL53L0X
│   ├── packet_handler.cpp   # Serial 패킷
│   └── crc16.cpp
└── lib/
```

라이브러리: `Adafruit PWM Servo Driver`, `pololu/VL53L0X`.

---

## 6. 업로드 절차 (중요)

```
1. 모든 쉴드 제거 (D0/D1 핀 간섭 방지)
2. pio run --target upload
3. 쉴드 재장착
4. pio device monitor 로 확인
```

---

## 7. 단독 검증 항목

- [ ] PCA9685 PWM 출력 + 서보 단순 구동 확인
- [ ] (ToF 센서 입고 후) VL53L0X I2C 측정 확인
- [ ] (전선 입고 후) 노트북 ↔ Arduino Serial 패킷 송수신 + CRC 검증
- [ ] 비상 동결 동작 확인

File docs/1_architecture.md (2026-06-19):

# 시스템 아키텍처

> 본 문서는 전체 시스템의 3계층 분산 구조와 각 계층의 책임 경계를 정의한다.
> 세부 인터페이스는 [gRPC 명세](3_grpc_interface.md), [Serial 명세](4_serial_protocol.md), [DSL 명세](5_dsl_spec.md) 참조.

---

## 1. 3계층 분산 구조

```
┌─────────────────────────────────────────────────────┐
│  Layer 3: AI 서버 (MSI EdgeXpert)                    │
│  - Whisper Large-v3 (한국어 STT)                     │
│  - Gemma 4 (멀티모달 LLM/VLM)                        │
│  - Qwen3-Embedding-8B (RAG)                          │
│  - FAISS Vector DB                                   │
│  - 역할: "무엇을 할지" 결정                            │
└─────────────────────────────────────────────────────┘
                        ↕ gRPC + Protobuf
┌─────────────────────────────────────────────────────┐
│  Layer 2: 노트북 (Control Hub)                       │
│  - YOLO-World 객체 탐지 (실시간, GPU)                 │
│  - OpenCV (캘리브레이션, 삼각측량)                     │
│  - IK 솔버 (Pieper 분해), 안전 검증                   │
│  - 카메라 기반 비상 정지                              │
│  - 역할: "어떻게 할지" 번역                            │
└─────────────────────────────────────────────────────┘
                        ↕ USB Serial (이진 + CRC-16)
┌─────────────────────────────────────────────────────┐
│  Layer 1: Arduino Mega 2560 (Hardware)               │
│  - PCA9685 (PWM 생성)                                 │
│  - VL53L0X ToF (그립 정밀 제어)                       │
│  - 역할: "실제 실행"                                  │
└─────────────────────────────────────────────────────┘
```

각 계층은 독립적으로 동작 가능해야 한다. 특히 **노트북의 비상 정지 판단은 AI 서버 응답에 의존하지 않는다** (네트워크 지연 시에도 안전 보장).

---

## 2. 책임 분리

| 책임 | 위치 | 비고 |
|---|---|---|
| 음성 → 텍스트 | AI 서버 (Whisper) | |
| 객체 탐지 (실시간) | 노트북 (YOLO-World) | 오픈 보캐뷸러리, Detection only, 마스크 없음 |
| 객체 의미 추론 (색·매칭) | AI 서버 (Gemma VLM) | |
| 명령 파싱 → JSON DSL | AI 서버 (Gemma) | |
| 좌표 변환·삼각측량 | 노트북 (OpenCV) | 결정적 작업 |
| 역기구학 (IK) | 노트북 | Pieper 분해 |
| 안전 검증 | 노트북 | DSL 4단계 검증 |
| 비상 정지 감시 | 노트북 (카메라 기반) | AI 서버 비의존 |
| 그립 정밀 제어 | 노트북 (ToF 폐루프) | |
| PWM 신호 생성 | Arduino (PCA9685) | |

설계 원칙: **의미 추론은 위로(AI 서버), 결정적·실시간 작업은 아래로(노트북/Arduino).**

---

## 3. 통신 채널 요약

| From → To | 프로토콜 | 데이터 | 주기 |
|---|---|---|---|
| AI 서버 ↔ 노트북 | gRPC + Protobuf | JSON DSL, 객체 정보 | 명령당 |
| 노트북 ↔ Arduino | USB Serial 이진 + CRC-16 | PWM 명령, 센서 값 | 50Hz |
| VL53L0X → Arduino | I2C | uint16 거리(mm) | 10Hz |
| 카메라 → 노트북 | USB | JPEG 프레임 | 30Hz |

---

## 4. 핵심 동작 시나리오

```
사용자: "빨간 컵을 책 옆에 놔줘"
   ↓ (노트북: 음성 캡처 → AI 서버로 전달)
음성 인식(Whisper) → 객체 매칭(Gemma VLM) → 의도 파싱(Gemma) → JSON DSL 생성
   ↓ (AI 서버 → 노트북)
DSL 검증(4단계) → 삼각측량 → 좌표 변환 → IK → 안전 검증
   ↓ (노트북 → Arduino, 50Hz)
S-curve 보간 → PWM 매핑 → 모터 제어 → 그립(ToF 폐루프) → 이동 → 놓기
```

---

## 5. 정량 목표

| 항목 | 목표값 |
|---|---|
| 그립 정밀도 | ±2mm (콜드스타트 보정 후) |
| 명령 → 그립 완료 | <10초 |
| 객체 인식 정확도 | ≥95% |
| 비상 정지 응답 | <100ms |
| 페이로드 | 150g |
| 팔 길이 | 450mm |
| 자유도 | 6-DOF |
| 제어 주기 | 50Hz |

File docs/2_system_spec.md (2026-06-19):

# 시스템 마스터 사양 — AI 기반 6-DOF 로봇팔

> **Voice-Controlled Autonomous Grasping Manipulator** · 대진대 캡스톤 디자인
> 본 문서는 프로젝트 전체의 마스터 레퍼런스다. 인터페이스 세부는 별도 문서로 분리한다:
> [architecture](1_architecture.md) · [gRPC](3_grpc_interface.md) · [Serial](4_serial_protocol.md) · [DSL](5_dsl_spec.md) · [conventions](6_conventions.md)

---

## 0. 한 줄 정의

한국어 음성 명령으로 객체를 인식하고 안전하게 그립하는 분산 AI 추론 기반 6-DOF 로봇팔.

전체 아키텍처·책임 분리·정량 목표는 [1_architecture.md](1_architecture.md) 참조.

---

## 1. AI 모델 스택

| 모델 | 역할 | 위치 |
|---|---|---|
| Whisper Large-v3 | 한국어 STT | AI 서버 |
| Gemma 4 (멀티모달) | LLM 추론 + VLM (객체 매칭, 의도 파싱, DSL 생성) | AI 서버 |
| YOLO-World (`yolov8m-worldv2`) | 실시간 객체 탐지 (오픈 보캐뷸러리, Detection only, 마스크 없음) | 노트북 (RTX 3050, CUDA) |
| Qwen3-Embedding-8B | RAG 벡터 임베딩 (dim 8192) | AI 서버 |

비전 처리 분담:
- **노트북 (결정적·실시간):** YOLO-World 탐지([laptop/docs/2_object_detection_model.md](../laptop/docs/2_object_detection_model.md)), OpenCV 삼각측량, ChArUco/ArUco, 좌표 변환, 비상 정지 감시.
- **AI 서버 (의미 추론):** 자연어-객체 매칭, 속성 인식, 의도 파싱, JSON DSL 생성.

---

## 2. 명령 처리 흐름

음성 → STT → 객체 매칭 → 의도 파싱 → JSON DSL → 노트북 검증 → IK → 모터 제어.
DSL 카탈로그·스키마·검증은 [5_dsl_spec.md](5_dsl_spec.md) 참조.

---

## 3. 수학적 모델링 — 4단계 변환 사슬

노트북은 매 동작마다 다음 4단계를 수행한다.

```
[입력] Gemma DSL + YOLO-World 픽셀 좌표
   ↓ ① 삼각측량 (Triangulation)        →  cv2.triangulatePoints, SVD
[3D 세계 좌표]
   ↓ ② 좌표계 변환 (Frame Transform)   →  동차변환 행렬 T (ArUco)
[로봇 베이스 좌표]
   ↓ ③ 역기구학 (Inverse Kinematics)   →  Pieper 분해
[6 관절각]
   ↓ ④ 보간 + PWM 매핑                 →  S-curve, 50Hz
[출력] Arduino PWM 명령 시퀀스
```

### 3.1 삼각측량
- 핀홀 카메라 모델 `s·[u,v,1]ᵀ = K·[R|t]·[X,Y,Z,1]ᵀ`
- 두 카메라 픽셀로 선형 시스템 구성 → SVD로 해 (`X = V[:,-1]`, 동차좌표 정규화)
- 구현: `cv2.triangulatePoints(P1, P2, pixel1, pixel2)`

### 3.2 좌표계 변환
- 동차변환 `T = [[R, t],[0,1]]`, `X_robot = T·X_world`
- `T`는 ArUco `estimatePoseSingleMarkers`로 산출, RAG에 저장.

### 3.3 역기구학 — Pieper 분해
부분 구형 손목 구조를 이용해 위치 IK(J1~J3)와 자세 IK(J4~J6)를 분리.

| 단계 | 내용 |
|---|---|
| 1 | 손목 중심 `p_wrist = p_target - d₆·R_target[:,2]` |
| 2 | `θ₁ = atan2(yw, xw)` |
| 3 | 평면 환원 `r=√(xw²+yw²)`, `s=zw-d₁` |
| 4 | `θ₃` 코사인 법칙 (`±` → elbow-up/down, `|D|>1`이면 도달 불가) |
| 5 | `θ₂ = atan2(s,r) - atan2(L₃sinθ₃, L₂+L₃cosθ₃)` |
| 6 | 자세 분리 `R₆³ = (R₃⁰)ᵀ·R_target` |
| 7 | YZY 오일러 분해 → θ₄, θ₅, θ₆ |
| 8 | 특이점 회피 (`|sinθ₅| < sin5°` → θ₄ 고정) |
| 9 | 8개 후보 중 최적해 선택 (관절 한계·충돌·워크스페이스 + 가중 비용 `J(θ)=Σwᵢ(θᵢ-θᵢ_cur)²`, 큰 서보일수록 wᵢ 작게) |

DH 파라미터 초기값(설계 도면 기반, 콜드스타트로 실측 갱신):

| 관절 | a(mm) | α(rad) | d(mm) | θ_offset |
|---|---|---|---|---|
| J1 | 0 | π/2 | 131.56 | 0 |
| J2 | 110.4 | 0 | 0 | -π/2 |
| J3 | 96.0 | 0 | 0 | 0 |
| J4 | 0 | π/2 | 73.18 | 0 |
| J5 | 0 | -π/2 | 66.39 | 0 |
| J6 | 0 | π/2 | 43.6 | 0 |

### 3.4 보간 + PWM 매핑
- S-curve `s(t)=3t²-2t³` (양 끝 속도 0 → 충격 없음), `θ(t)=θ_cur+s(t)·(θ_tgt-θ_cur)`
- 시간 분할 `T = max|Δθ|/60`, `N = T×50`
- PWM 매핑은 [6_conventions.md](6_conventions.md) 참조.

---

## 4. 콜드스타트 — Visual-Kinematic 캘리브레이션

3D 프린트 누적 오차(±10~15mm)를 로봇 자가 측정으로 ±2mm까지 보정.

| 단계 | 내용 |
|---|---|
| 1 내부 캘리브레이션 | ChArUco 보드 20~30쌍 → `cv2.calibrateCamera` (K, distortion) |
| 2 외부 캘리브레이션 | 베이스 ArUco → 카메라-로봇 변환 T |
| 3 관절 한계 측정 | 각 관절 ±방향 회전, 물리 한계 감지 |
| 4 자세 격자 순회 | 75~100점, 각 점 IK 이동 후 그리퍼 ArUco 측정 → {θₖ, p_expected, p_measured} |
| 5 DH 최적화 | Levenberg-Marquardt, `C(DH)=Σ‖FK(θₖ,DH)-p_measured‖²`, `scipy.optimize.least_squares(method='lm')` |
| 6 RAG 등록 | Qwen3 임베딩 → FAISS 저장 (메타: 보정일, 평균오차, DH) |

검증: `ε_avg < 5mm` 합격, 아니면 재캘리브레이션.

---

## 5. 그립 자세 결정 — PCA 기반

객체 형상에 따라 그립 전략 차등 (둥근 컵=top-down, 펜=길이방향 수직, 책=옆 가장자리).

- 포인트 집합 공분산 `C`의 고유값 분해 → 주축 v₁, 부축 v₂
- 이심률 `e=√(λ₁/λ₂)`, 주축각 `α=atan2(v₁[1],v₁[0])`
- `e<1.5`→top-down(θ₄=0), `e>2.5 & 폭>20`→side(θ₄=90), 중간→angled(θ₄=45)
- `θ₅ = α_robot - 90°`, 그리퍼 폭 = `minor_width + 10mm`
- **YOLO-World는 마스크가 없으므로** bbox 종횡비 근사 + Gemma VLM 질의로 대체.

---

## 6. 안전 메커니즘 — 이중 구조

### 6.1 메커니즘 A — ToF 폐루프 (그립 정밀 제어 전용, 비상 정지 아님)
```
v_descent = Kp·(d_measured - d_target)·min(1, d_measured/100),  Kp=0.05, d_target=5mm
그립 트리거: d < 10mm
```
3단계: open-loop 빠른 접근 → ToF 폐루프 하강 → 그립.

### 6.2 메커니즘 B — 카메라 기반 비상 정지 (4계층 Defense-in-Depth)

| 계층 | 감지 |
|---|---|
| 1 | 사람 침입 (person bbox ∩ workspace) |
| 2 | 객체 급격 이동 (>500 mm/s) |
| 3 | 경로상 장애물 (waypoint-obstacle <30mm) |
| 4 | 타겟 시야 사라짐 (최근 3프레임 부재) |

비상 정지 동작: 관절 동결 → 그리퍼 상태 유지 → 명령 잠금 → AI 서버 알림 → 사용자 확인 → 홈 복귀.

응답 시간 예산: YOLO-World ~20ms + 검증 <5ms + 송신 <1ms + 서보 정지 <5ms = **<100ms**.

> ToF는 비상 정지에 사용하지 않는다. 비상 정지는 카메라 기반이며 AI 서버 응답에 의존하지 않는다.

---

## 7. RAG 지식 베이스 스키마 (요약)

```yaml
rag_db:
  dh_parameters:    { J1:[a,α,d,θ_off], ... }
  joint_limits:     { J1:[min,max], ... }
  workspace:        { x_range, y_range, z_range }
  camera_calibration: { cam1:{K,R,t,dist}, cam2:{...} }
  object_database:  { red_cup:{weight_g, dims_mm}, book:{...}, pen:{...} }
  metadata:         { calibration_date, avg_error_mm }
```

---

## 8. 학술적 차별화 포인트

1. **Code-as-Policies** — LLM이 제한된 DSL을 직접 생성 (RT-2, ProgPrompt 계열)
2. **Visual-Kinematic Self-Calibration** — 로봇 자가 측정 운동학 보정
3. **RAG-Grounded** — FAISS+Qwen3로 LLM 환각 차단, 모든 수치를 검증된 사실로 grounding
4. **카메라 기반 Defense-in-Depth Safety** — 4계층 독립 검증

핵심 참고: Zhang(2000) 카메라 캘리브레이션, Hartley&Zisserman(2003) 삼각측량, Denavit-Hartenberg(1955), Pieper(1968) IK, Marquardt(1963) LM, Liang et al.(2022) Code-as-Policies.

---

## 9. 위험 요소 (요약)

| 위험 | 대응 |
|---|---|
| YOLO-World GPU 부족 | Detection-only, batch=1 |
| 3D 프린트 강도 | 카운터웨이트 2kg, 페이로드 제한 150g |
| J3 토크 부족 | DS3235 업그레이드 옵션 |
| ToF 노이즈 | 이동평균 필터(5샘플), 비반사 매트 |
| LLM 환각 | 4단계 DSL 검증 |
| AI 서버 지연 | 노트북 비상 정지 독립 |
| 카메라 가려짐 | 두 카메라 중 하나만 보여도 동작 |

---

> 본 마스터 사양은 구현 진행에 따라 갱신된다. 각 컴포넌트의 모듈 단위 명세는
> [arduino/docs](../arduino/docs/README.md) · [ai_server/docs](../ai_server/docs/README.md) · [laptop/docs](../laptop/docs/README.md) 참조.

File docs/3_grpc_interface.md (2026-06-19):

# gRPC 인터페이스 명세 — AI 서버 ↔ 노트북

> **공통 합의 문서.** AI 서버(EdgeXpert)와 노트북은 이 명세를 단일 진실 공급원(single source of truth)으로 삼는다.
> proto 원본은 향후 `shared/proto/robot_arm.proto`에 두고, 양측이 동일 파일에서 코드를 생성한다.

---

## 1. 개요

| 항목 | 값 |
|---|-----|
| 프로토콜 | gRPC + Protobuf (proto3) |
| 기본 포트 | 50051 |
| 직렬화 | Protocol Buffers |
| 연결 형태 | 노트북 = 클라이언트, AI 서버 = 서버 |

---

## 2. 서비스 정의

```protobuf
syntax = "proto3";

service RobotArmAI {
  // 단방향 요청-응답: 음성+비전 → JSON DSL
  rpc PlanGrasp(GraspPlanRequest) returns (GraspPlanResponse);

  // 양방향 스트림: 노트북 상태 보고(50Hz) + AI 서버 알림
  rpc StreamSafetyAlert(stream LaptopStatus) returns (stream SafetyAlert);

  // 연결 확인 (3초 주기)
  rpc Heartbeat(HeartbeatRequest) returns (HeartbeatResponse);
}
```

---

## 3. 메시지 정의

```protobuf
message GraspPlanRequest {
  bytes audio_data = 1;          // WAV
  string audio_format = 2;
  bytes camera1_frame = 3;       // JPEG
  bytes camera2_frame = 4;       // JPEG
  repeated DetectedObject detections = 5;  // 노트북 YOLO-World 결과
  RobotState current_state = 6;
  int64 timestamp_ms = 7;
}

message DetectedObject {
  int32 id = 1;
  string class_name = 2;
  Bbox bbox_cam1 = 3;
  Bbox bbox_cam2 = 4;
  Point3D position_3d_mm = 5;    // 노트북 삼각측량 결과
}

message Bbox   { float x = 1; float y = 2; float w = 3; float h = 4; }
message Point3D { float x_mm = 1; float y_mm = 2; float z_mm = 3; }

message RobotState {
  repeated float joint_angles_deg = 1;  // 6개
  bool gripper_closed = 2;
}

message GraspPlanResponse {
  string dsl_script = 1;         // JSON 인코딩된 DSL (5_dsl_spec.md 참조)
  float confidence = 2;
  int32 inference_time_ms = 3;
  string reasoning = 4;          // Chain-of-Thought
}

message LaptopStatus {
  float tof_distance_mm = 1;
  RobotState state = 2;
  int64 timestamp_ms = 3;
}

message SafetyAlert {
  string reason = 1;
  int64 timestamp_ms = 2;
}
```

---

## 4. 메시지 흐름

| RPC | 방향 | 설명 |
|-----|---|---|
| `PlanGrasp` | 노트북 → AI 서버 → 노트북 | 음성+카메라+탐지 결과 전송 → JSON DSL 수신 |
| `StreamSafetyAlert` | 양방향 스트림 | 노트북이 50Hz로 상태 보고, AI 서버는 필요 시 알림 |
| `Heartbeat` | 노트북 ↔ AI 서버 | 3초 주기. **3초 무응답 시 노트북이 독립적으로 비상 정지** |

---

## 5. 책임 경계 (중요)

- **삼각측량은 노트북이 수행한다.** AI 서버에는 이미 3D 좌표(`position_3d_mm`)가 채워진 `DetectedObject`가 전달된다. AI 서버는 좌표를 다시 계산하지 않는다.
- **AI 서버가 반환하는 DSL은 좌표가 아니라 객체 ID 기반 명령이다.** (`target: "cup_2"`) 실제 좌표 해석·IK는 노트북 책임.
- **DSL 검증은 노트북이 수행한다.** AI 서버 출력은 신뢰하지 않고 화이트리스트/파라미터/시퀀스 검증을 거친다 → [5_dsl_spec.md](5_dsl_spec.md).

---

## 6. 단위·규약

- 모든 길이: **mm**
- 모든 각도: **degree** (proto 필드명에 `_deg` 명시)
- 타임스탬프: **Unix epoch milliseconds** (`int64`)
- 좌표계 정의는 [6_conventions.md](6_conventions.md) 참조.

---

## 7. TODO (구현 단계)

- [ ] `shared/proto/robot_arm.proto` 작성 및 양측 코드 생성 스크립트 정비
- [ ] 타임아웃/재시도 정책 확정 (현재 안: timeout 10s, heartbeat 3s)
- [ ] 대용량 프레임 전송 시 압축/스트리밍 여부 검토

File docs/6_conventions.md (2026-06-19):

# 공통 규약 — 좌표계 / 단위 / 명명

> 모든 계층이 동일한 단위와 좌표 약속을 따른다. 변환 버그의 대부분은 단위/좌표 불일치에서 발생하므로 여기서 못박는다.

---

## 1. 단위

| 물리량 | 단위 | 비고 |
|---|---|---|
| 길이 | **mm** | 예외 없음 |
| 각도 | **degree** (외부 인터페이스) / **radian** (내부 수학) | gRPC/Serial 필드는 `_deg`. IK 내부 계산은 rad. 경계에서 변환. |
| 시간 | gRPC: Unix epoch **ms** / Arduino: `millis()` 상대 ms | |
| 무게 | **g** | |
| 각속도 | **deg/s** | 최대 60 deg/s |

---

## 2. 좌표계

### 2.1 로봇 베이스 좌표계 (기준 프레임)

- 원점: 로봇 베이스 중심
- Z축: 위쪽(중력 반대)
- X/Y: 베이스 평면. ArUco 마커 정렬 기준으로 확정.

### 2.2 작업공간 (config 기준값)

| 축 | 범위 (mm) |
|----|---|
| x | [-200, 200] |
| y | [50, 350] |
| z | [50, 250] |

### 2.3 카메라 ↔ 로봇 변환

- 카메라 좌표 → 로봇 좌표는 동차변환 행렬 `T`로 통일.
- `T`는 ArUco 외부 캘리브레이션으로 산출, RAG에 저장하여 재사용.

---

## 3. 관절 명명 및 한계

| 관절 | 이름 | 서보 | 한계 (deg, 초기값) |
|---|---|---|---|
| J1 | base | DS3235 Pro | [-90, 90] |
| J2 | shoulder | DS3235 Pro | [-90, 90] |
| J3 | elbow | DS3218 Pro | [-90, 90] |
| J4 | wrist_pitch | DS3218 Pro | [-90, 90] |
| J5 | wrist_roll | MG90S | [-90, 90] |
| J6 | gripper_rot | MG90S | [-90, 90] |
| — | gripper (개폐) | MG90S | open/close |

> 한계값은 콜드스타트 관절 한계 측정으로 실측값으로 갱신된다.
>
> **실측 갱신(2026-06):** 위 `[-90, 90]`은 원래 설계값이며, 실제 매핑은 각 관절을 **0°~180°** 가동범위로 잡고 관절별 0°/180° 펄스폭 실측값([arduino/docs/1_servo_calibration.md](../arduino/docs/1_servo_calibration.md))을 사용한다. 서보가 **끝 스톱이 없는 마그네틱(절대위치) 엔코더형**(무전원 시 무한 회전, 전원 시 위치 복귀)이라 **소프트웨어 관절 한계가 필수**다.

---

## 4. PWM 매핑 규약

```
PWM_μs    = 1500 + (θ_deg / 90) * 500     # 0°→1500, +90°→2000, -90°→1000
PCA_value = int(PWM_μs * 4096 / 20000)    # 50Hz=20000μs, 12bit
```

> **주의 — 위 균일 공식은 원래 설계값이며 실측으로 대체되었다.** 실제 매핑은 관절별 실측 0°/180° 펄스폭([arduino/docs/1_servo_calibration.md](../arduino/docs/1_servo_calibration.md), 예: J1 0°=600µs, 180°=2740µs)을 사용하고 가동범위는 **0~180°**다. 서보가 끝 스톱 없는 마그네틱 엔코더형이므로 소프트웨어 관절 한계가 필수다.

---

## 5. 객체 ID 명명

- 탐지 객체는 `<class>_<index>` 형식 (예: `cup_2`, `book_1`).
- DSL의 `target`은 이 ID를 사용한다 (좌표 직접 지정 금지).

---

## 6. 코드/파일 명명

| 대상 | 규칙 |
|---|---|
| Python 모듈/함수 | `snake_case` |
| Python 클래스 | `PascalCase` |
| C++ 파일 | `snake_case.cpp/.h` |
| 상수 | `UPPER_SNAKE_CASE` |
| proto 메시지 | `PascalCase`, 필드 `snake_case` |
| docs 파일 | `snake_case.md` |

---

## 7. 언어

- 문서·주석: 한국어 (기능 명세), 코드 식별자: 영어.
- 사용자 음성 명령: 한국어.

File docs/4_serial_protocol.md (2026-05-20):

# USB Serial 프로토콜 명세 — 노트북 ↔ Arduino

> **공통 합의 문서.** 노트북(Python `struct`)과 Arduino(C++ `struct`)가 동일한 바이트 레이아웃을 공유한다.
> 양쪽 구조체 정의가 어긋나면 통신 전체가 깨지므로, 변경 시 반드시 이 문서를 먼저 갱신한다.

---

## 1. 개요

| 항목 | 값 |
|---|-----|
| 물리 계층 | USB Serial (CDC) |
| Baudrate | 115200 |
| 패킷 크기 | 35 bytes (양방향 동일) |
| 무결성 | CRC-16-CCITT (poly 0x1021, init 0xFFFF) |
| 엔디안 | little-endian |
| 시작 마커 | `0xAA` |
| 송신 주기 | 노트북→Arduino: 명령 시 / Arduino→노트북: 10Hz (ToF) |

---

## 2. 패킷 구조

### 2.1 노트북 → Arduino (Command Packet, 35 bytes)

```c
struct CommandPacket {
    uint8_t  header;           // 0xAA
    uint8_t  command_type;     // 0x01=joint, 0x02=gripper, 0x03=emergency
    uint32_t timestamp_ms;
    float    joint_angles[6];  // 6 × 4 bytes
    uint8_t  gripper_state;    // 0=open, 1=close
    uint16_t crc16;
};
```

### 2.2 Arduino → 노트북 (Sensor Packet, 35 bytes)

```c
struct SensorPacket {
    uint8_t  header;           // 0xAA
    uint8_t  packet_type;      // 0x01=sensor, 0x02=ack, 0x03=error
    uint32_t timestamp_ms;
    uint16_t tof_distance_mm;
    float    joint_angles[6];  // 현재 자세 피드백
    uint8_t  gripper_state;
    uint8_t  emergency_button;
    uint16_t crc16;
};
```

> 두 구조체 모두 35 bytes로 맞춘다. Python `struct` 포맷: `'<BBI6fBBH'` (Sensor 기준).
> C++ 측은 `#pragma pack(1)` 또는 수동 직렬화로 패딩을 제거해야 35 bytes가 보장된다.

---

## 3. 명령/패킷 타입 코드

| command_type | 의미 |
|---|---|
| 0x01 | joint 각도 명령 |
| 0x02 | gripper 개폐 |
| 0x03 | emergency (즉시 동결) |

| packet_type | 의미 |
|---|---|
| 0x01 | sensor (정기 보고) |
| 0x02 | ack (명령 수신 확인) |
| 0x03 | error |

| tof 특수값 | 의미 |
|---|---|
| 0xFFFE | ToF 측정 실패 |

---

## 4. CRC-16-CCITT

```c
uint16_t computeCRC16(uint8_t *data, size_t length) {
    uint16_t crc = 0xFFFF;
    for (size_t i = 0; i < length; i++) {
        crc ^= (uint16_t)data[i] << 8;
        for (int j = 0; j < 8; j++) {
            if (crc & 0x8000) crc = (crc << 1) ^ 0x1021;
            else crc <<= 1;
        }
    }
    return crc;
}
```

- CRC는 **마지막 2바이트(crc16 필드)를 제외한** 전체 바이트에 대해 계산한다.
- 수신 측은 CRC 불일치 시 패킷을 폐기하고 error 처리한다.

---

## 5. 단위·규약

- 관절 각도: **degree** (`float`)
- 거리: **mm** (`uint16`)
- 타임스탬프: `millis()` 기반 ms (`uint32`) — 노트북 epoch와 별개이며 상대 시간 용도

---

## 6. 안전 관련

- `command_type=0x03` (emergency) 수신 시 Arduino는 현재 PWM을 **동결(freeze)**한다 — 0으로 만들지 않는다(중력 낙하 방지).
- `emergency_button` 필드는 하드웨어 비상 버튼 상태. 노트북은 매 sensor 패킷에서 이를 확인한다.

---

## 7. TODO (구현 단계)

- [ ] `arduino/include/packet_protocol.h` 와 `laptop/src/communication/packet_codec.py` 동기 작성
- [ ] 패킷 손실/재동기화 정책 (header 재탐색) 구현
- [ ] ack 타임아웃 및 재전송 정책 확정

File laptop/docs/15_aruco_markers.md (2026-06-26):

# ArUco 마커 스킴 — 로봇팔

> 로봇팔에 부착하는 ArUco 마커 정의. 인쇄물: `calibration/arm_markers.pdf`
> 생성기: `calibration/make_arm_markers.py` (크기 변경 시 값만 수정 후 재생성)

---

## 1. 사전(dictionary)

| 용도 | 사전 |
|---|---|
| 캘리브레이션 보드(ChArUco) | `DICT_5X5_100` |
| **로봇 마커(베이스·추적)** | **`DICT_6X6_250`** |

→ 서로 다른 사전이라 동시에 써도 **충돌 없음**.

## 2. 마커 목록

| id | 크기 | 역할 | 부착 위치 |
|:--:|:----:|---|---|
| **0** | 70mm | **기준 변환 T (단계 ⑤)** — 카메라↔로봇 | **고정 베이스**(안 움직이는 맨 아래) |
| 1 | 40mm | 추적/콜드스타트 | J1 이후 링크 |
| 2 | 40mm | 〃 | J2 링크 |
| 3 | 40mm | 〃 | J3 링크 |
| 4 | 40mm | 〃 | J4 링크 |
| 5 | 40mm | 〃 | J5 링크 |
| 6 | 40mm | 〃 | J6/손목 |
| 7 | 40mm | 〃 | 그리퍼 |
| 8~12 | 40mm | 여분 | 필요 위치 |

> 위 배치는 권장안. 실제로 붙인 id↔위치를 확정하면 이 표를 갱신할 것.

## 3. 부착 가이드

- **베이스(id 0)**: 반드시 **움직이지 않는 부분**에. 이게 로봇 좌표계의 기준. 평평한 면에 크게(70mm) 부착해 포즈 정확도 확보.
- **추적(id 1~)**: 각 링크/그리퍼에 1개씩. **곡면이면 작게 그대로 붙이거나 평평한 관절 하우징**에. 카메라에 보이는 면으로.
- 공통: **구겨지지 않게 평평하게**, 마커 주변 **흰 여백(quiet zone) 유지**(테두리까지 바짝 자르지 말 것), 무광 권장.

실물 부착 예 — 베이스 id0(70mm)와 각 링크 추적 마커(id1~, 40mm)를 카메라 보이는 면에 부착

## 4. 인쇄

- **반드시 100% 배율**(맞춤설정 100%). 인쇄 후 **50mm 스케일 선**으로 검증.
- id 0은 70mm, id 1~12는 40mm로 출력되어야 함(각 마커 한 변 측정).

## 5. 활용 (다음 단계)

- **단계 ⑤**: id 0 으로 `cv2.aruco.estimatePoseSingleMarkers`(또는 solvePnP) → 카메라→로봇 변환 T 산출 → 저장. 이후 물체 3D를 로봇 좌표로 변환.
- **콜드스타트/추적**: id 1~ 로 각 링크 포즈를 측정해 FK 예측과 비교(운동학 보정), 동작 중 추적.
- 마커 한 변 실측값(mm)을 코드에 정확히 입력해야 거리(포즈)가 맞음.

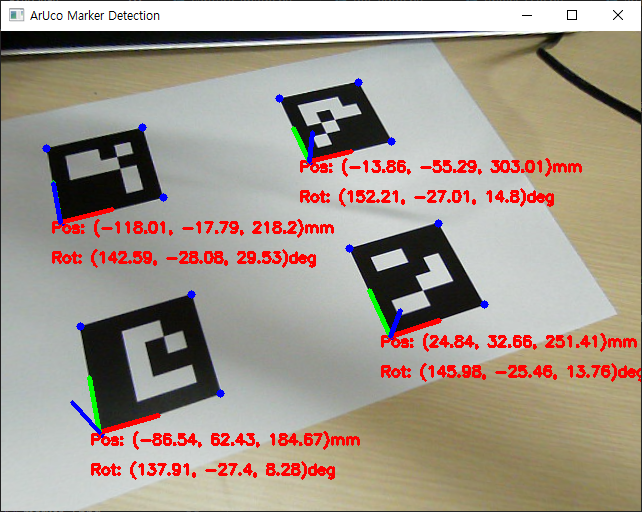
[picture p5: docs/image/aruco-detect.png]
ArUco 포즈 검출 — 각 마커의 위치(mm)·회전(deg)을 실시간 산출


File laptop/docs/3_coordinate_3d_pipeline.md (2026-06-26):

# 3D 좌표 파이프라인 — 2D 픽셀에서 로봇 좌표까지

> 두 카메라의 **2D 픽셀 탐지**를 **로봇 베이스 기준 3D 좌표(mm)** 로 변환하는 전체 단계를 정의한다.
> 이 3D 좌표가 IK(역기구학)의 입력이 되어, 물체를 집기 위한 관절각을 계산한다.
> 수식 세부는 [system_spec §6](../../docs/2_system_spec.md), [laptop README §3](README.md) 참조.

---

## 어떻게 캘리브레이션했나 (방법 요약)

깊이를 알려면 **두 카메라가 같은 점을 본 각도 차이(시차)** 가 필요하고, 그러려면 두 카메라의 **내부 특성(K·왜곡)과 상대 위치(R·T)** 를 먼저 알아야 한다. 이를 알아내는 과정이 캘리브레이션이다.

**왜 ChArUco 보드인가** — 일반 체스보드는 일부가 가리거나 화면 밖으로 나가면 코너 전체를 못 쓴다. **ChArUco**(체스보드 + ArUco 마커 융합)는 각 코너에 **고유 ID**가 박혀 있어, **부분만 보여도** 어떤 코너인지 식별된다 → 다양한 각도/거리 촬영에 강건하고 정확하다.

**실제 절차** (2페이지 위저드, 도구는 OpenCV `cv2.aruco`)
1. **촬영** — `DICT_5X5_100` · **6×8 칸** · 사각 30mm/마커 23mm 보드를 양 카메라로 **20~30쌍** (위치·기울기·거리 다양하게). 화면 가장자리까지 커버.
2. **내부 캘리브레이션** — `CharucoDetector`로 코너 검출 → `cv2.calibrateCamera` → 카메라별 K·왜곡. *(실측 재투영오차 L0.44 / R0.49px)*
3. **스테레오 캘리브레이션** — 양쪽 공통 코너 → `cv2.stereoCalibrate` → R·T·투영행렬 P1·P2. *(0.60px, 베이스라인 588mm)*
4. **검증** — 보드 30mm 칸을 삼각측량으로 복원해 오차 측정. *(0.32mm, 스케일 0.9998 → 통과)*
5. 결과를 `stereo_calib.npz`에 저장해 재사용. 이후 물체의 좌/우 픽셀을 `triangulatePoints`로 3D화.

| ChArUco 보드(인쇄본) | 양 카메라 코너 검출 |
|:---:|:---:|
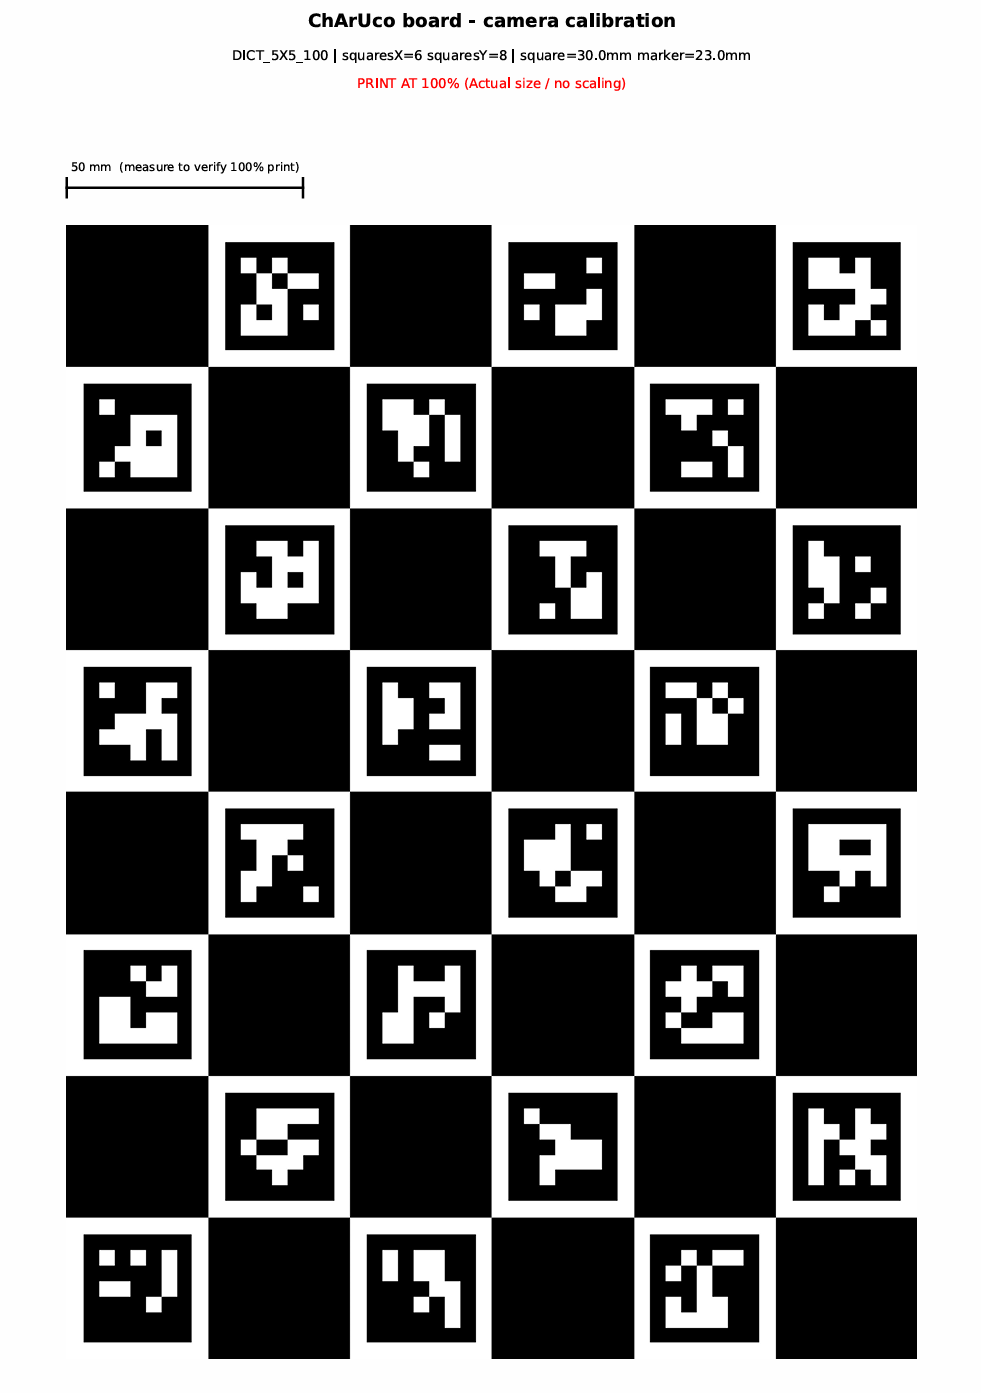
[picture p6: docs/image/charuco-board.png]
ChArUco 보드 — DICT_5X5_100, 6×8칸, 사각 30mm·마커 23mm. 100%로 인쇄해 평판에 부착
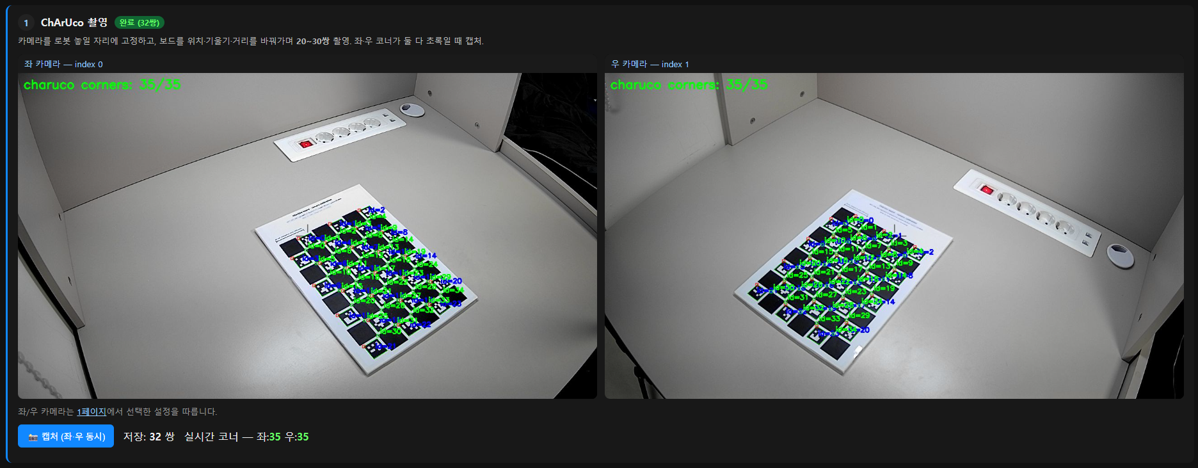
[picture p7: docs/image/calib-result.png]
ChArUco 코너 검출 — 양 카메라가 보드의 내부 코너를 인식(초록), corners NN/35
|  |  |

> 🎬 데모 영상: [로봇팔 3D 인식 과정 — 스테레오 삼각측량](https://drive.google.com/file/d/1MBFXagUDMlq_0g1TG0gAltHQs-gzVrMP/view?usp=sharing)

> 카메라 배치가 바뀌면(상호 위치 변경, USB 재연결로 좌/우 교체 등) **1~3을 다시** 해야 한다. 절차 상세 → [14_setup_procedure.md](14_setup_procedure.md).

---

## 0. 전체 흐름 한눈에

```
[카메라 2대] ──YOLO-World──▶ 2D 픽셀 (u,v) ×2
                                   │
   ① 내부 캘리브레이션 (K, 왜곡)    │  ChArUco 보드
   ② 스테레오 외부 캘리브레이션      │  ChArUco 동시
   ③ 좌우 대응(매칭)               │  같은 물체 짝짓기
                                   ▼
   ④ 삼각측량 ──▶ 3D (X,Y,Z) [카메라 좌표, mm]
                                   │
   ⑤ 로봇 좌표 변환 (T) ──ArUco──▶ 3D [로봇 베이스 좌표, mm]
                                   ▼
                              IK 입력 → 관절각
```

---

## 1. 단계별 명세

### 단계 ⓪ — 2D 픽셀 탐지  ✅ (완료)
- **목적:** 각 카메라에서 물체 위치를 픽셀로 검출.
- **방법:** YOLO-World (`armvision/detector.py`) → bbox 중심 (u, v).
- **산출:** 카메라별 `{class, conf, bbox, center(u,v)}`.
- **한계:** 화면 픽셀일 뿐 깊이/실제 위치 없음. → 이하 단계로 3D화.

### 단계 ① — 카메라 내부 캘리브레이션 (Intrinsics)  ✅
- **목적:** 각 카메라의 **초점거리·주점(K)** 과 **렌즈 왜곡** 산출. 왜곡 보정 없이는 좌표 오차 큼.
- **방법:** **ChArUco 보드**(체스보드 + ArUco 융합 — 일부 가려져도 코너 식별, 부분 검출에 강건)를 다양한 각도·거리로 **20~30쌍** 촬영 → 코너 검출 → 캘리브레이션.
- **OpenCV:** `cv2.aruco.CharucoDetector`(`armvision/charuco.py`) → 코너/ID → `cv2.calibrateCamera` → `K, dist`.
- **산출:** 카메라별 `K`(3×3), `distortion`(5).
- **준비물:** 인쇄된 ChArUco 보드 — `DICT_5X5_100`, **6×8 칸**, 사각 **30mm** / 마커 **23mm**(내부 코너 35개). 생성: `calibration/make_targets.py`.
- **검증:** 재투영 오차 < ~0.5px.

### 단계 ② — 스테레오 외부 캘리브레이션 (Extrinsics)  ✅
- **목적:** **두 카메라의 상대 위치/자세(R, t)** 산출. 삼각측량의 필수 입력.
- **방법:** 두 카메라가 **동시에** 같은 ChArUco 보드를 보는 쌍 여러 장 → 양쪽 공통 코너로 스테레오 캘리브레이션.
- **OpenCV:** `cv2.stereoCalibrate` → `R, T`(좌→우 변환), 이어서 `cv2.stereoRectify`. (`calibration/calibrate_stereo.py` → `stereo_calib.npz`)
- **산출:** `R, T`, 그리고 각 카메라의 **투영행렬 P1, P2**(= K[R|t]).
- **검증:** epipolar 제약 오차 작은지 확인.

### 단계 ③ — 좌우 대응 (Correspondence)  ✅
- **목적:** 좌 카메라의 물체와 우 카메라의 **같은 물체**를 짝짓기 (삼각측량은 같은 점의 좌/우 픽셀이 필요).
- **방법(난이도순):**
  1. 클래스 + 위치 휴리스틱 (같은 class, epipolar 선 근처) — 간단 시작.
  2. **Epipolar 기하** 이용: `cv2.computeCorrespondEpilines` 로 후보 제한.
  3. 외형 특징 매칭(필요 시).
- **산출:** 짝지어진 `(u,v)_left ↔ (u,v)_right` 쌍.
- **메모:** 한쪽에서만 탐지된 물체는 이 단계에서 보완(다른 쪽 epipolar 선 탐색).

### 단계 ④ — 삼각측량 (Triangulation)  ⬜
- **목적:** 좌/우 픽셀 쌍 → **3D 점(카메라 좌표계, mm)**.
- **방법:** 핀홀 모델 `s·[u,v,1]ᵀ = K[R|t][X,Y,Z,1]ᵀ`, 두 카메라로 선형식 구성 → SVD.
- **OpenCV:** `cv2.triangulatePoints(P1, P2, pts_left, pts_right)` → 동차좌표 → 정규화.
  ```python
  pts4d = cv2.triangulatePoints(P1, P2, ptsL, ptsR)
  pts3d = (pts4d[:3] / pts4d[3]).T   # (N,3) mm
  ```
- **산출:** 물체별 3D 좌표 (카메라 좌표계).
- **검증:** 알려진 거리의 물체로 오차 측정.

### 단계 ⑤ — 로봇 좌표 변환 (Frame Transform)  ⬜
- **목적:** 카메라 좌표 → **로봇 베이스 좌표**(IK가 쓰는 기준). 동차변환 `T`.
- **방법:** 로봇 베이스에 **ArUco 마커** 부착 → 카메라로 인식 → 카메라-로봇 변환 산출.
- **OpenCV:** `cv2.aruco`(`estimatePoseSingleMarkers`) → `R, t` → `T=[[R,t],[0,1]]`.
  `X_robot = T · X_camera`.
- **산출:** 물체의 **로봇 베이스 기준 (X,Y,Z) mm**. → IK 입력.
- **저장:** `T`, 캘리브레이션 결과는 재사용을 위해 RAG/파일에 저장.

---

## 2. 단계 → 결과 요약

| 단계 | 입력 | 산출 | OpenCV | 상태 |
|:---:|---|---|---|:---:|
| ⓪ | 영상 | 2D (u,v) | YOLO-World | ✅ |
| ① | ChArUco | K, 왜곡 | calibrateCamera | ✅ (오차 L0.44/R0.49px) |
| ② | ChArUco(동시) | R,T,P1,P2 | stereoCalibrate | ✅ (오차 0.60px, 베이스 588mm) |
| ③ | 좌·우 탐지 | (u,v) 쌍 | epilines | ✅ (`stereo3d.py` epipolar 매칭) |
| ④ | (u,v) 쌍, P1,P2 | 3D(카메라) | triangulatePoints | ✅ (보드 30mm를 0.32mm 오차로 복원, scale 0.9998) |
| ⑤ | 3D(카메라), ArUco | 3D(로봇) | aruco | ⬜ |

→ 이후: **3D(로봇) → IK(Pieper) → 관절각 → S-curve → PWM → Arduino** (이미 캘리브레이션된 서보 펄스 매핑 사용).

---

## 3. 준비물 (하드웨어)

- **ChArUco 보드** (`DICT_5X5_100`, 6×8, 사각 30mm/마커 23mm) — 단계 ①②③. 평판에 평평히 부착.
- **ArUco 마커** (`DICT_6X6_250`, 로봇 베이스 id0 70mm 등, 크기 mm 측정) — 단계 ⑤⑥, [15_aruco_markers.md](15_aruco_markers.md).
- 카메라 2대는 **고정**(촬영 중 위치 불변) — 캘리브레이션 유효성 유지.

---

## 4. 정밀도 메모

- 3D 프린트 누적 오차로 설계 DH 그대로면 ±10~15mm → 콜드스타트 visual-kinematic 보정으로 ±2mm 목표
  (system_spec §7). 본 파이프라인의 캘리브레이션이 그 토대.
- 단계 ①②의 캘리브레이션 품질이 전체 3D 정확도를 좌우 → ChArUco 보드 촬영을 충분/다양하게.

---

## 5. 구현 순서 제안 (작은 단위)

1. ✅ 단계 ① 한 카메라 내부 캘리브레이션 + 결과 저장.
2. ✅ 두 카메라 각각 ① 완료 → 단계 ② 스테레오.
3. ✅ 단계 ④ 삼각측량을 **고정 ChArUco 코너**로 먼저 검증(물체 매칭 전).
4. ✅ 단계 ③ 물체 대응 붙이기 → 실제 물체 3D.
5. ⬜ 단계 ⑤ ArUco로 로봇 좌표 변환 (베이스 마커 부착 후).

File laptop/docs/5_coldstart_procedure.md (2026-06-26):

# 콜드스타트 절차 — 비전-운동학 자가보정

> **목적:** 실물 로봇팔에 전원을 막 켰을 때(cold start), CAD 도면 없이
> **`{명령한 관절각/펄스, 카메라로 측정한 마커 3D}`** 만으로 **실제 운동학**(관절 축의 위치·방향,
> 명령↔실제 각도 관계)을 복원한다. 3D 프린트 누적오차 + 서보 비선형으로 실물은 CAD와 다르므로,
> 이를 측정으로 잡아내야 디지털 트윈(시뮬)이 실물과 일치한다.

관련: [4_measurement_validation.md](4_measurement_validation.md)(측정 신뢰성) · [6_digital_twin_safety.md](6_digital_twin_safety.md)(시뮬 안전모델) · [3_coordinate_3d_pipeline.md](3_coordinate_3d_pipeline.md)(3D 측정)

---

## 1. 계층 역할 — 보정은 어디서 하나

3계층에서 **콜드스타트 보정은 노트북(제어 허브)의 책임**이다. AI 서버는 언어만 담당하며, 원시 측정·펄스를 받아 보정하지 않는다.

```
AI 서버   : 자연어 → 의도/명령(DSL)               ["무엇을" 할지]
   ↓ gRPC
노트북    : 비전·운동학·콜드스타트 보정·안전(충돌모델)·펄스생성   ["어떻게" 할지]  ← 보정 여기
   ↓ Serial
Arduino   : 펄스 실행
```

**보정 데이터 흐름** (둘 다 노트북으로 모여 보정된 안전 모델을 만든다):
```
[실물 구동 + 카메라 측정 + 펄스 기록]  ──┐
                                          ├─▶ 노트북: 콜드스타트 → 정확한 FK + 안전 검증층
[시뮬 결과(디지털트윈·충돌모델)]      ──┘
```
→ AI 명령은 이 **안전 검증층을 통과해야** 실물로 간다.

---

## 2. 절차 (6단계)

| 단계 | 내용 | 도구/산출 |
|:--:|---|---|
| 1 | **스테레오 캘리브레이션**(ChArUco) + **카메라→로봇 변환 T**(원점 = id1 = J1축) | 2페이지 ①~⑤ |
| 2 | **ArUco 마커 부착**: id0 베이스, id1~7 각 링크 | — |
| 3 | **데이터 수집**: 4페이지 `검증 시퀀스` — **한 관절씩 단독**으로 각도를 바꾸며 매 자세에서 8개 마커 3D를 스테레오 측정 → CSV `{idx, J1~J6, id0_x…id7_z}` | `calibration/validation_data/run{1,2}_*.csv` |
| 4 | **관절 축 복원**: 단독 회전 시 말단 마커가 그리는 **원을 피팅**(SVD 평면 + Kasa 원) → 회전축(방향 ω·축상의 점 q) + **명령↔실제 각도 보정계수 k** | `calibration/coldstart.py` |
| 5 | **PoE 순기구학(FK) 구성·검증**: 복원 축으로 FK를 만들어 측정 자세를 예측 → **잔차 = sim-real gap** | `coldstart.py` |
| 6 | **결과 사용**: gap을 디지털 트윈 **안전 마진**으로 연동 | [6_digital_twin_safety.md §5](6_digital_twin_safety.md) |

> **펄스를 기록하는 이유:** 각도는 서보 보정이 한 겹 얹힌 추상이고, **펄스가 "진짜 명령"** 이다.
> `{펄스, 측정 3D}`를 직접 보정하면 "명령 75°가 실제 68°(k=0.913)" 같은 비선형을 펄스 단위로 잡는다.

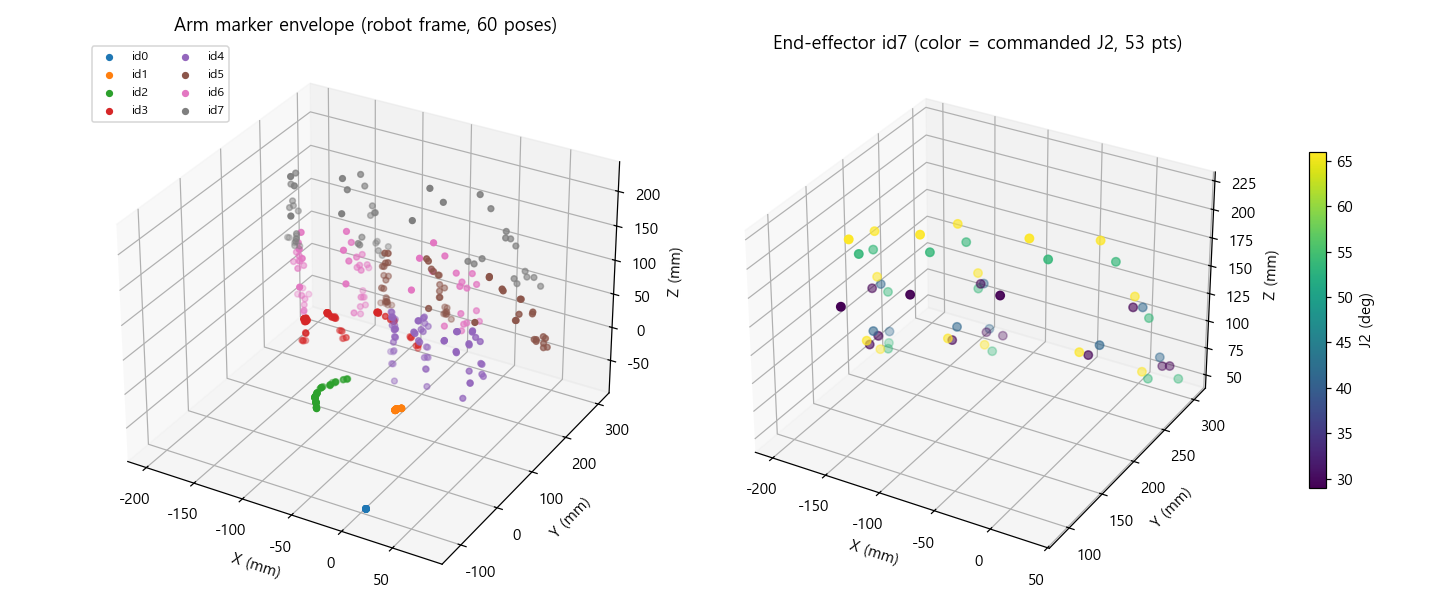
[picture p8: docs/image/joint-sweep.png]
관절 스윕 수집 데이터 — 좌: 60자세에서 측정한 팔 마커 분포(로봇 기준), 우: 말단 마커 궤적(색=명령 J2·J3)


---

## 3. 이론 — PoE(Product of Exponentials)

각 관절을 단독 회전시키면 그 위(distal)의 마커는 **고정 축에 대한 원**을 그린다. 원을 피팅해 **스크류 축** $S_i=(\omega_i, q_i)$ 와 보정계수 $k_i$ 를 얻으면, 임의 자세의 마커 위치는

$$p(\theta) = e^{[S_1]\theta_1} e^{[S_2]\theta_2} \cdots e^{[S_n]\theta_n}\, p_{home}, \qquad \theta_i = k_i(\text{cmd}_i - \text{home}_i)$$

로 예측된다(공간형 PoE). DH 파라미터화보다 **측정한 축을 직접 쓰므로** 본 데이터에 자연스럽다.

| 산출 | 의미 |
|---|---|
| $\omega_i$ (원 평면의 법선) | 관절 회전축 방향 |
| $q_i$ (원 중심) | 축이 지나는 점 |
| $k_i$ (관측 회전 / 명령 각도) | **명령↔실제 보정계수**(서보 비선형·기어비 흡수) |

J1 축 복원 예 (말단 마커가 그리는 원 + 복원된 수직 회전축):

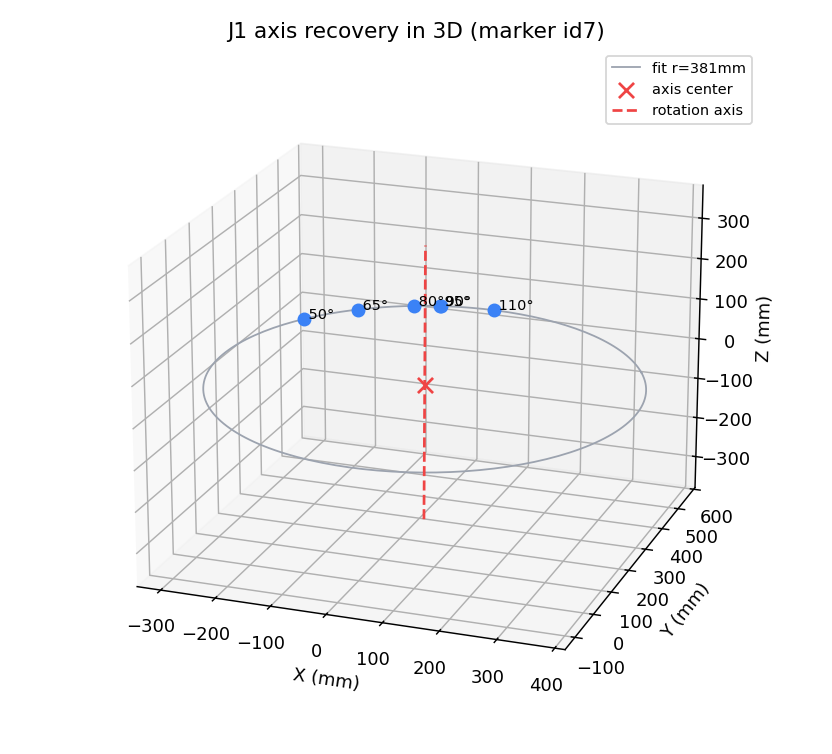
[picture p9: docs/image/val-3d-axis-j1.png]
J1 축 복원


---

## 4. 현재 결과 (정직하게 — 부분 보정)

`run2_30pose.csv` 기준:

| 관절 | 결과 | 비고 |
|:--:|---|---|
| **J1** | ✅ 복원 (반경 380mm, **k=0.913**, 각잔차 2.66°) | 명령 75°→실제 68°(서보 ~9% 과명령) |
| **J4** | ✅ 양호 (반경 149mm, 1.73°) | |
| J2·J3 | ❌ 불량 | 마커가 피치축에 근접·가림 → 원이 작아 노이즈 |
| J5·J6 | ❌ 미복원 | 말단 마커 id7 가림 |

| 핵심 산출 | 값 |
|---|-----|
| 비전 측정 잡음 바닥 | σ ≤ 0.3 mm (완벽) |
| **FK 잔차 = sim-real gap** | **평균 12.4 mm · 최악 30.8 mm** |
| 원인 | 서보 비선형 ~3°가 긴 레버에서 cm급 증폭 |

> **즉, 현재 콜드스타트는 "완전한 6축 운동학 모델"이 아니라 "sim-real gap 크기 + J1 보정계수를 측정한 부분 보정"** 이다.
> gap(30mm)을 안전 마진으로 쓰기엔 충분했다.

---

## 5. 미완 + 완성 로드맵

**원인:** 마커가 피치축(J2·J3)에 너무 가깝고, 손목(J5·J6) 회전 시 말단 마커가 가려진다.

**완성하려면:**
1. **데이터 보강** — 마커를 축에서 멀리 재배치, 또는 **팔이 아래를 향하는 전용 스윕**(말단 마커가 보이게)으로 J2·J3·J5·J6 수집. 각도당 반복 측정.
2. **번들 최적화** — 독립 원피팅을 초기값으로, 모든 축을 동시에 맞추는 **LM 최적화**(scipy)로 체인 누적오차 최소화.
3. **펄스 기준 보정** — `{펄스, 측정 3D}`로 펄스→실제자세 직접 매핑(서보 비선형 정밀 보정).

---

## 6. 재현

```
1) 2페이지 ①~⑤  (스테레오 보정 + 변환 T, 원점=id1)
2) 4페이지 제어 → 검증 시퀀스  → run_*.csv 다운로드
3) python calibration/coldstart.py <csv> [그리퍼길이mm]
     → 관절별 축·k, FK 잔차(sim-real gap), 바닥/그리퍼 도달 분석 출력
```

> 데이터·수치는 2026-06 실측 기준(run1 24자세·run2 30자세). 환경(카메라·조립) 변경 시 재측정.

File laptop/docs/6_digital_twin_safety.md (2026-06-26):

# 디지털 트윈 안전 검증 + 자가학습 — 비전 보정 시뮬레이션을 통한 충돌 안전 모델

> **요지:** STL 3D 시뮬레이터를 **디지털 트윈**으로 삼아, 비전(콜드스타트)으로 실물에 보정하고,
> 시뮬에서 **스스로 충돌 데이터를 생성·학습**하여, AI 명령을 실물 실행 전에 검증하는 안전층을 만든다.
> 핵심 기여는 ① 저비용 웹캠+시뮬로 sim-to-real 보정 루프를 닫고,
> ② **불확실 자세 기반 능동학습으로 모델이 스스로 약점을 찾아 성장**시키며,
> ③ 안전 마진을 **측정된 sim-real gap**에 연동해 "시뮬 안전 ⇒ 실물 안전"을 정량 보증한 것이다.

관련: [4_measurement_validation.md](4_measurement_validation.md) · [8_arm3d_simulator.md](8_arm3d_simulator.md) · [3_coordinate_3d_pipeline.md](3_coordinate_3d_pipeline.md)

---

## 1. 개념 — 하나의 디지털 트윈으로 묶이는 조각들

"시뮬레이션으로 미리 학습해 안전 확보"와 "캘리브레이션/콜드스타트"는 별개가 아니라 **하나의 디지털 트윈**이다.

```
   3D 시뮬(CAD 이상 모델)  ──예측──▶  "이 자세는 위험"
          ▲                              │  믿어도 되려면?
          │ 보정(콜드스타트)              ▼
   비전 측정(실물 관측) ◀── 실물이 실제로 그렇게 움직이는가
```

본 연구가 구현한 전체 파이프라인:

```
디지털트윈(STL 시뮬) → 비전 콜드스타트 보정(sim-real gap 측정)
   → C-space 충돌지도(L0, 자가생성) → 충돌예측 신경망(L1)
   → 능동학습(불확실 자세 자가선별로 약점 보강) → AI 명령 검증층
```

각 단계는 확립된 문헌에 1:1로 대응한다 — 디지털 트윈, 운동학 캘리브레이션, **구성공간(Configuration Space, Lozano-Pérez 1983)**, 학습 기반 충돌검사(learned collision checking), 능동학습(active learning). 본 연구의 새로움은 이 전체 루프를 **표준 웹캠 2대 + 인쇄 마커 + STL 시뮬**이라는 저비용 구성으로 재현하고, 그 산출물을 **LLM 명령의 안전 검증층**으로 사용한 데 있다.

---

## 2. 디지털 트윈 — 시뮬 내장 충돌 감지

4페이지 STL 시뮬레이터(`arm3d.html`, Three.js)에 충돌 감지를 내장했다. 모든 부품은 STL 정점을 가지므로, **정점을 점군으로 활용**한다.

### 2.1 바닥 충돌
- 각 부품 STL 정점을 ~400점 다운샘플 → 매 프레임 월드 좌표로 변환 → **최저 y가 바닥평면(격자, y=0) 대비 여유**.
- 받침대(운동학 루트)는 설계상 바닥에 닿으므로 제외, **움직이는 링크만** 검사.
- 제어 모드에서 실시간 HUD(여유 mm·안전/위험/충돌) + 충돌점 마커.

### 2.2 자기 충돌 (그리퍼 ↔ 팔 본체)
- **손(그리퍼) 자동 식별:** 직렬 팔 체인이 처음 갈라지는 부품(`gripper base`)부터 모든 자손을 한 덩어리로 묶는다.
- 손의 점들을 **비인접 링크의 로컬 OBB(bounding box)에 투영**해 부호거리(음수=침투) 계산.
- 손 자신·장착 링크(손목)·미리깅 정적 부품은 제외 → 구조적 오탐 방지.

> 이 충돌 코어(`_collideOnce`)는 실시간 HUD·일괄 스윕·능동학습 라벨링이 **모두 공유**하여 일관성을 보장한다.

---

## 3. C-space 충돌 지도 (L0 — 자가생성 데이터)

관절 공간을 쓸어 각 자세의 충돌을 라벨링하면 **구성공간(C-space) 장애물 지도**가 된다. 모든 모션 플래닝의 기반 개념이다.

### 3.1 어떤 관절을 쓸 것인가 — 축 분석
관절 축을 분석해 충돌과 무관한 관절을 가려냈다:

| 관절 | 축 방향 | 충돌 영향 | 처리 |
|:--:|:--:|---|---|
| J1 | `[0,−1,0]` 수직 | 높이·부품거리 **불변** | **제외**(수직 yaw → 충돌 불변, 스윕 낭비) |
| J2·J3·J4 | 수평 피치 | 바닥 주 결정 | 격자+랜덤 |
| J5 | `[−0.11,−0.99,0]` 준수직 | 손 수평 스윙 → **자기충돌(주효)** | 랜덤 |
| J6 | `[−1,0,0]` 수평 피치 | 그리퍼를 바닥으로(방향상) — 짧아 영향 작음 | 랜덤 |

> **실측 특징 중요도(RandomForest, 100k):** J2 **41.6%** · J3 **32.0%** · J4 13.9% · J5 **10.0%** · J6 **2.6%**.
> 바닥은 J2·J3가 지배. **손목 중 J5가 J6보다 영향이 크다** — 극단 J5(0·180°)에서 손이 팔 본체로 스윙해 자기충돌(J5=60~120° 중립에선 자기충돌 ≈0). J6의 '그리퍼를 바닥으로' 효과는 방향상 맞으나 그리퍼가 짧아 통계적 비중은 작다.

> **발견:** 초기 스윕은 손목(J5·J6)을 고정해 손목발(發) 충돌을 빠뜨렸다. 둘을 넣자 충돌률이 6.5%→10.0%로 오르고, **손목 회전으로 그리퍼가 팔 본체(base·elbow)에 부딪히는 자기충돌(1.7%)** 이 처음 드러났다. (자기충돌을 주도한 건 J6보다 **J5**였다.)

### 3.2 격자 vs 랜덤
- **격자(J2·J3·J4, 5°):** 50,653 조합. 2D 히트맵 시각화용.
- **랜덤(J2~J6, Monte Carlo):** 5차원은 격자 폭발(37⁵≈6,900만)이라 **랜덤 샘플링이 정석**. 100,000 샘플.

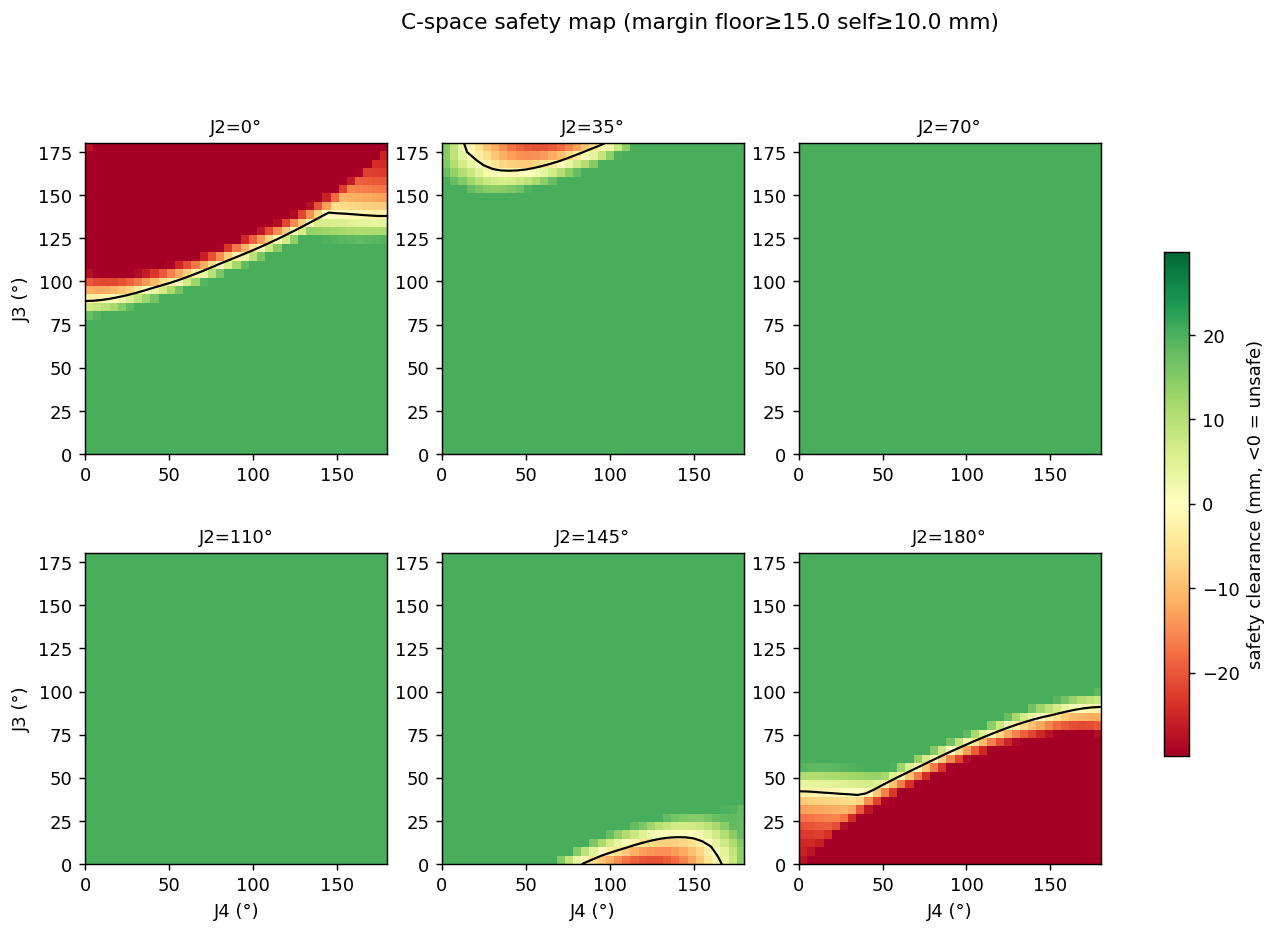
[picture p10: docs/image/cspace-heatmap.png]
C-space 안전 히트맵


> 🎬 데모 영상 — 디지털트윈 C-space 충돌 검증: [①](https://drive.google.com/file/d/1vYuo53dGs2aWkysy1HClAFdfzunhA5IU/view?usp=sharing) · [②](https://drive.google.com/file/d/1E0i8ZytOhljyalwJxXthOAcU_MwYzIW0/view?usp=sharing)

J2별 패널: 초록=안전, 빨강=위험, 검은선=충돌경계. J2≈70~110°(팔이 수직)에선 전 영역 안전(바닥 무관), J2≈0·180°(앞/뒤로 접음)+극단 J3에서 바닥 충돌.

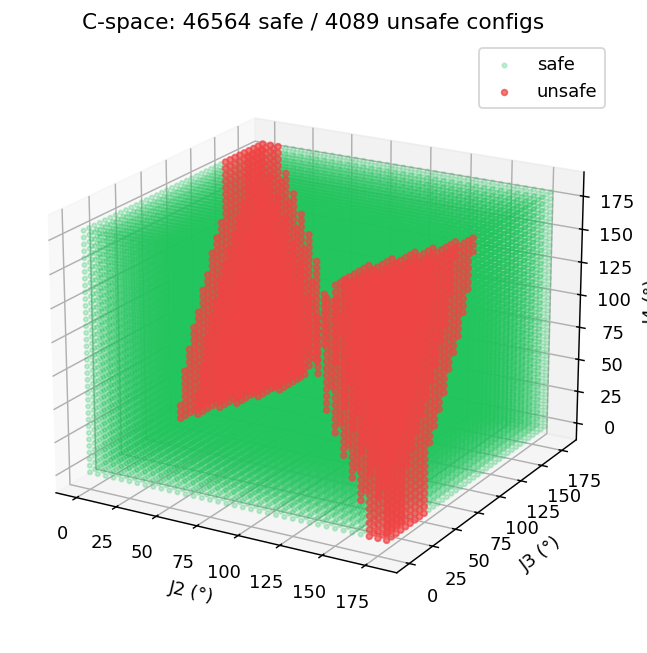
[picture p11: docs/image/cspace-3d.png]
C-space 3D


(J2,J3,J4) 공간에서 위험 영역(빨강)이 **두 날개**로 분리되는 전형적 C-space 장애물 형상.

---

## 4. 충돌예측 신경망 (L1 — 자가학습 모델)

자가생성 데이터로 관절각(J2~J6) → 안전/위험을 예측하는 신경망(MLP 64×64)을 학습한다. 목적은 **AI가 메시 충돌검사 없이 마이크로초 만에 자세 안전성을 질의**하는 검증층.

| 지표 | 값 |
|---|-----|
| 학습 데이터 | 100,000 자세 (시뮬 자가생성, 사람 라벨 0) |
| 정확도 | 98.97% |
| 위험 재현율(임계 0.5) | 97.54% |
| **안전 임계(0.14) 재현율** | **99.53%** (미탐 17/3579) |
| 추론 속도 | **0.8 µs/질의** |

안전이 핵심이므로(위험을 놓치면 로봇 파손) 확률 임계값을 낮춰 **위험 재현율을 최대화**(미탐 최소화, 오경보 감수)한다.

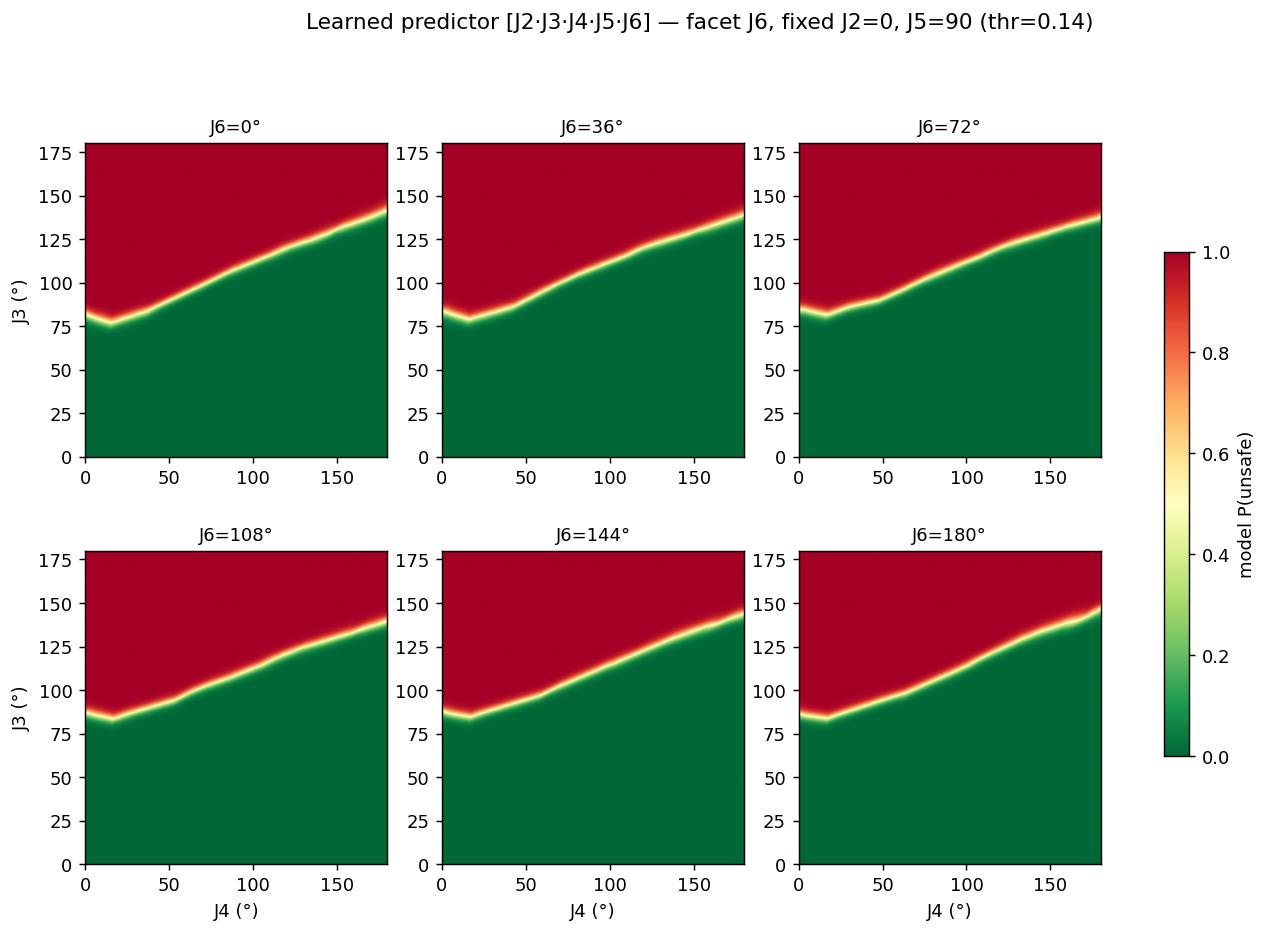
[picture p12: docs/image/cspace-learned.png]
학습된 충돌예측기


J6별 패널: 색=모델 예측 P(위험). **J6(그리퍼 피치)가 커질수록 위험 영역이 확장** — 그리퍼가 아래로 내려가 바닥에 닿는 효과를 모델이 학습했다.

---

## 5. sim-real gap 마진 — 시뮬과 실물을 잇는 키스톤 (#4)

C-space 지도는 **이상적 CAD 기하 + 명령 각도**로 계산된다. 실물은 (a) 서보 비선형 ~3°, (b) 3D 프린트 누적오차로 어긋난다. 따라서 "시뮬 안전 ⇒ 실물 안전"이 성립하려면:

$$\text{안전(실물)} \iff \text{시뮬 여유} > \delta\;(\text{측정된 sim-real gap})$$

이 δ를 **콜드스타트(비전-운동학 자가보정)로 실측**했다 → [4_measurement_validation.md](4_measurement_validation.md), `coldstart.py`:

| 측정 | 값 |
|---|-----|
| 비전 측정 잡음 바닥 | σ ≤ 0.3 mm (완벽) |
| **콜드스타트 FK 잔차(sim-real gap)** | **평균 12.4 mm · 최악 30.8 mm** |
| 원인 | 서보 각도 비선형 ~3° → 긴 레버에서 cm급 |

→ **바닥 마진 = 30 mm**(외부 평면, 최악 gap 전부), **자기 마진 = 15 mm**(상대 기하라 오차 일부 상쇄 → 절반). 이 마진을 반영하면 위험률 14.3%.

**잔존 위험 정량화:** 100k 모델에서 안전 임계로 놓친 위험 17개의 실제 침투깊이는 **중앙값 1.9 mm·최악 10.4 mm** → 전부 30 mm 보정 마진 *안*. 즉 **모델이 위험을 놓쳐도 실물 충돌 경계엔 여전히 여유**가 있어 안전이 보증된다. (데이터를 40k→100k로 늘리니 최악 미탐이 16.9→10.4 mm로 줄어, 데이터 증가가 안전 보증을 직접 강화함을 확인.)

---

## 6. 능동학습 — 모델이 스스로 약점을 찾아 성장 ★

본 연구의 자가학습 서사의 핵심이다. **균일 랜덤 대신, 모델이 가장 헷갈려하는 자세(결정경계, P(위험)≈0.5)를 골라 그것만 라벨링**한다.

### 6.1 데이터 효율 (능동 vs 랜덤)
기존 100k를 오라클 풀로 한 공정 비교(RandomForest, 3시드 평균):

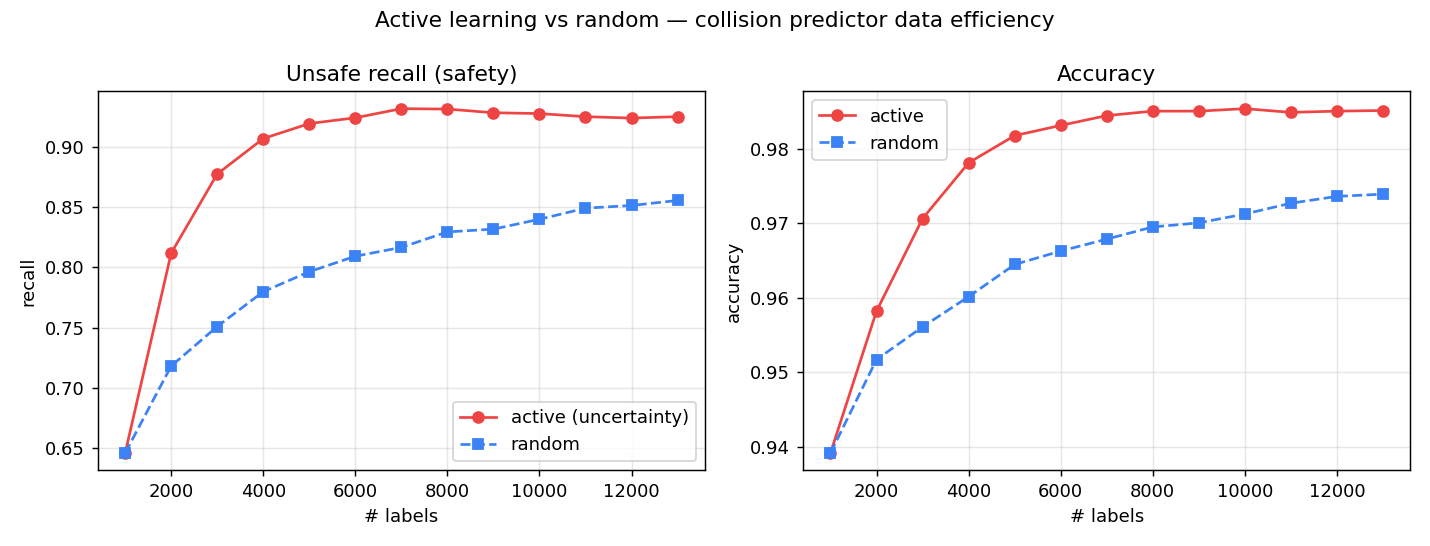
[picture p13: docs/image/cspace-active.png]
능동 vs 랜덤


→ **능동이 랜덤의 최종 성능(13,000 라벨)에 단 3,000 라벨에서 도달 → 라벨 77% 절약.** 전 구간 능동이 랜덤을 7~12%p 앞선다.

### 6.2 실운용 자가학습 루프 (★ 핵심)
데모(풀 내부)를 넘어, **풀 밖의 새 자세를 실제 시뮬로 라벨링**하는 진짜 루프를 구현했다:

```
Python: 모델이 불확실(P≈0.5)한 자세 N개 선별 → cspace_query.csv
   ↓
시뮬(4p 🏷 질의 라벨링): 각 자세 충돌검사 → cspace_labeled.csv
   ↓
Python: 누적·재학습·오라클 평가 → 다음 질의 …  (반복)
```

소량 시드(2000, 랜덤)에서 시작해 라운드마다 모델이 스스로 약점을 제안·보강:

| 라운드 | 누적 라벨 | 정확도 | 위험 재현율 | 비고 |
|:--:|:--:|:--:|:--:|---|
| 1 (시드, 랜덤) | 2,000 | 97.51% | 91.99% | 출발점 |
| 2 (능동) | 3,500 | 98.49% | 93.99% | |
| 3 (능동) | 5,000 | 98.88% | **97.58%** | **균일 100k 성능 도달** |
| 4 (능동) | 6,500 | 99.08% | 97.49% | 수렴 |

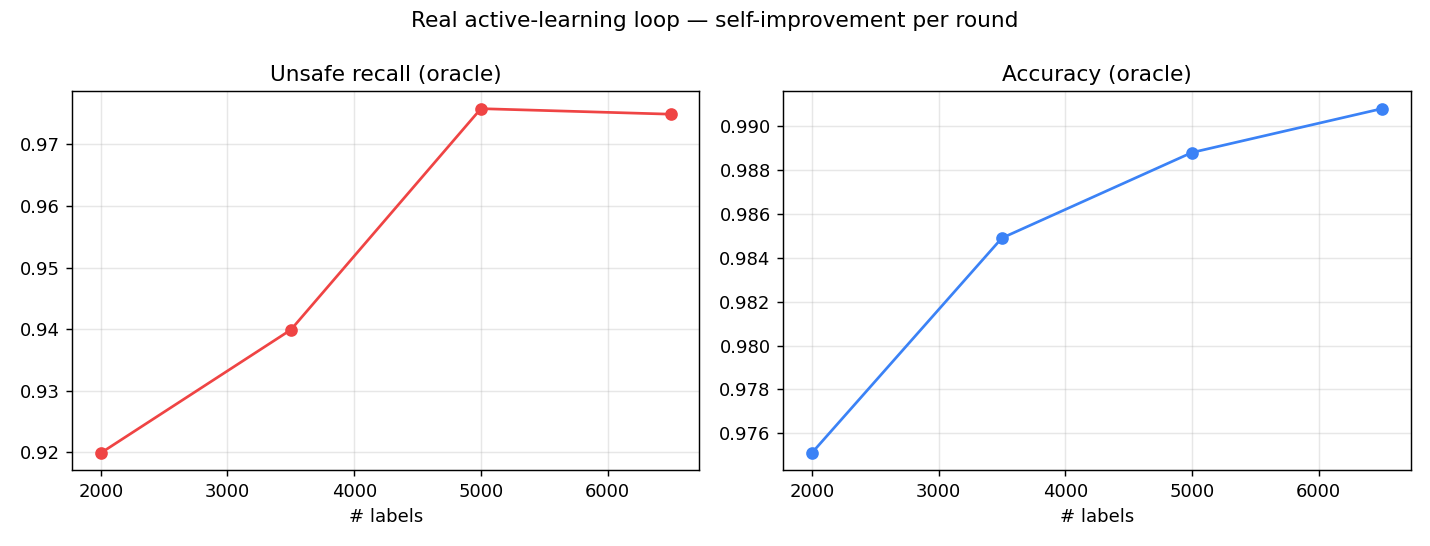
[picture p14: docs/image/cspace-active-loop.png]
실운용 자기개선 곡선


> **🎯 핵심 결과: 5,000 라벨(전체 데이터의 5%)로 균일 100k 모델과 동일한 재현율(97.5%)에 도달.**
> 추가된 자세의 위험 비율이 15%→35%로 상승 = **능동학습이 실제로 위험/안전 경계에 데이터를 집중**시키고 있다는 증거. "로봇이 시뮬에서 스스로 헷갈리는 자세를 제안하고, 디지털 트윈이 충돌 여부로 답하며, 모델이 약점을 보강하며 성장"하는 자가학습 루프가 작동함을 실측으로 증명했다.

### 6.3 자가학습의 정직한 위치 (사다리)
| 단계 | 내용 | 본 연구 |
|:--:|---|:--:|
| L0 | 전수/랜덤 열거 → C-space 지도 | ✓ |
| L1 | 자가생성 데이터로 학습된 충돌예측 모델 | ✓ |
| **능동** | 모델이 라벨 대상을 스스로 선별(자기개선) | ✓ |
| L2 | 보정된 트윈에서 RL 모션 정책 | 향후 |

본 연구는 **시스템 식별 + 능동학습**으로, RL(L2)은 아니나 "자가생성 데이터 → 학습 → 자기개선"이 모두 *과장 없이 사실*이다. 보정된 디지털 트윈을 이미 갖췄으므로 L2 RL의 전제조건은 충족되어 있다.

---

## 7. AI 명령 검증층 — 할루시네이션 처리

학습된 모델의 가장 강력한 역할은 AI의 두뇌가 아니라 **안전 검증층**이다:

```
사용자 명령 → [LLM이 동작 생성] → [충돌예측 모델 0.8µs 검증] → 통과만 실물로
                  (할루시네이션 가능)        (결정론적·측정근거 마진)
```

LLM이 팔을 부수는 자세를 제안해도, 시뮬에서 학습한 검증층이 실물 실행 전에 잡아낸다. 이것이 자연어 제어의 **할루시네이션 처리**다.

---

## 8. 정량 요약

| 영역 | 지표 | 값 |
|---|---|-----|
| 측정 | 비전 잡음 바닥 | σ ≤ 0.3 mm |
| 보정 | sim-real gap(콜드스타트 FK 잔차) | 평균 12.4·최악 30.8 mm |
| L0 | C-space 데이터 | 격자 50,653 + 랜덤 100,000 |
| L1 | 5D 모델 정확도 / 안전재현율 | 98.97% / 99.53% |
| L1 | 추론 속도 | 0.8 µs/질의 |
| L1 | 잔존 위험(놓친 위험 최악 침투) | 10.4 mm (< 마진 30 mm) |
| 능동 | 라벨 효율(데모) | 77% 절약 |
| 능동 | 실운용 수렴 | 5,000 라벨(5%)로 100k 성능 |

---

## 9. 학술적 의의

1. **검증 가능한 안전 모델** — 단순 2D 재투영오차가 아니라, **3D 강체 운동학으로 보정된 디지털 트윈**에서 충돌 안전을 학습. 마진이 *측정된* sim-real gap에 묶여 "시뮬 안전 ⇒ 실물 안전"을 정량 보증.
2. **자가학습 실증** — 시뮬이 스스로 데이터를 생성하고(L0), 모델이 학습하며(L1), **불확실 자세를 자기선별해 약점을 보강(능동)** — 전체 루프를 실운용으로 닫았다.
3. **저비용 재현** — 웹캠 2대 + 인쇄 마커 + STL 시뮬로 디지털 트윈 보정 + C-space + 학습 안전층을 구성, 고가 트래커·물리엔진 없이 sim-to-real 안전 검증을 시연.

---

## 10. 한계 및 향후

- **미리깅 정적 부품:** 링크의 `.t`(윗면) 반쪽이 리깅되지 않아 자기충돌 대상에서 제외. 고정 결합 시 충돌 검사 포함 가능.
- **콜드스타트 피치축:** J2·J3는 마커가 피치축에 근접·가림으로 축 복원 불량, J5·J6은 말단 마커 가림으로 미복원. 아래방향 전용 스윕으로 보강 필요.
- **라벨 비용:** 시뮬 라벨이 싸서 능동학습의 실익(정확도)보다 아키텍처 시연 가치가 큼. 라벨이 비싼 실물 검증으로 확장 시 능동학습의 실용 가치 부각.
- **향후:** ① J2/J3 콜드스타트 보강으로 자세별 정밀 마진 ② L2 RL 모션 정책 ③ AI 서버 자연어 파이프라인에 검증층 연결.

---

## 11. 재현 방법

| 단계 | 명령 / 동작 |
|---|---|
| C-space 격자 | 4p 제어 → `🗺 격자(J2·J3·J4)` → `cspace_grid.csv` → `python calibration/cspace_analysis.py <csv>` |
| C-space 랜덤(5D) | `🎲 랜덤(J2~J6)` → `cspace_rand.csv` → `python calibration/cspace_learn.py <csv>` |
| 능동학습 데모 | `python calibration/cspace_active.py <csv>` |
| 실운용 능동 루프 | `cspace_active_loop.py init/query/merge/plot` ↔ 4p `🏷 질의 라벨링` (§6.2) |

> 데이터·수치는 2026-06 실측 기준. 환경(카메라·조립) 변경 시 재측정.

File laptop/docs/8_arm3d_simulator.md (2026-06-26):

# 4페이지 — STL 3D 시뮬레이터 & 실물 연동

> 팀원이 만든 **STL 부품을 브라우저에서 직접 조립**해 6-DOF 로봇팔 디지털 트윈을 만들고,
> 관절을 움직여 **실제 로봇팔과 동시에 구동**하는 페이지. (`/arm3d/`)
> 구현: `armvision/templates/armvision/arm3d.html` (Three.js, 단일 파일) + 서버측 STL/저장/시리얼 엔드포인트.
> AI 서버 연동 **직전 단계**까지 완성된 상태.

---

## 0. 한눈에

```
cad/*.stl ──로드──▶ [조립] 부품 배치 ──▶ [결합] 면대면 관절 정의 ──▶ 저장(assembly.json)
                                                          │
                                                  [제어] 관절 슬라이더
                                                          ├─▶ 3D 로봇팔 회전 (항상)
                                                          └─▶ (연동 ON) 각도→펄스 → 시리얼 → 실제 서보
```

세 모드를 상단 세그먼트(**조립 · 결합 · 제어**)로 전환한다.

---

## 제작 방법 — 참조 설계 → CAD → 디지털 트윈

이 디지털 트윈은 **실물과 똑같은 STL 부품**으로 만들었다. 과정은 세 단계다.

**① 참조 설계 (목표 형상 확정)**
- C-브래킷 6-DOF 코봇 형태의 **참조 설계도/사진**을 기준으로, 어떤 링크(base·shoulder·elbow·wrist·endeffector·gripper)가 어떻게 연결되는지 정했다.
- 관절 축 방향(J1 베이스 회전, J2~J4 평면 피치, J5 롤, J6 그리퍼)도 이 설계에서 도출.

참조 설계 — 6-DOF 링크 구성과 관절 J1~J6, 링크 치수(arm span 350mm)

실물 6-DOF 로봇팔 — 3D 프린팅 링크 조립, 각 링크에 추적용 ArUco 마커(id1~) 부착

> 🎬 데모 영상: [3D 시뮬레이터 동작 — 조립·리깅·제어](https://drive.google.com/file/d/1hU2PR68-Gy2XqOHGjDWO9H2JxIDRQaFw/view?usp=sharing)

**② CAD 모델링 → STL (팀원 작업)**
- 팀원이 CAD(예: Fusion/SolidWorks)로 각 링크를 **실측 치수(mm)** 로 모델링하고 **STL로 익스포트** → `cad/`에 18개 파일.
- 각 부품은 **자기 원점 기준**이라, 불러오면 한 곳에 겹쳐 보인다(아래 조립으로 정렬).

**③ 브라우저에서 조립 → 리깅 (본 시뮬레이터)**
- STL을 로드해 **조립 모드**로 대략 배치 → **결합 모드**에서 **면대면 결합**(맞물릴 원통 + 맞닿을 평면)으로 부품을 정확히 결합.
- 회전해야 할 곳은 **회전 결합**으로, 고정할 곳은 **고정 결합**으로 지정 → **6관절 리깅 완료**.
- 각 회전 결합에 **모터 채널·펄스(us0/us180)** 를 매핑해두면, 제어 모드에서 실물과 연동된다.

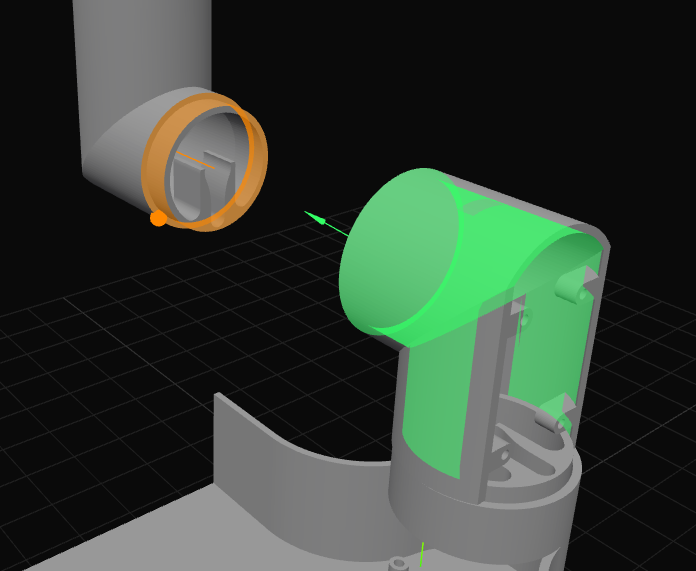
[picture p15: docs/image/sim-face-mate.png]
면대면 결합 — 두 부품의 원통(주황·초록)을 선택해 동심+면일치로 결합


6관절 조립 완료 — 회전 결합으로 리깅, 시안색 선은 고정(잠금) 연결 표시
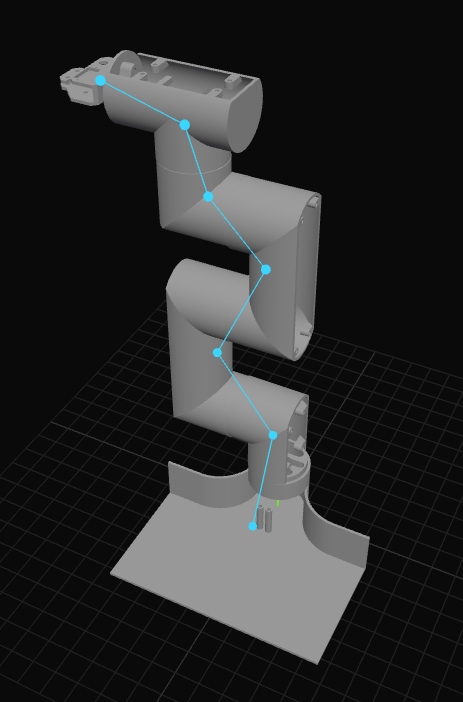
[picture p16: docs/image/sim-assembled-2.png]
다른 각도에서 본 조립 완료 모습


이렇게 만든 트윈은 **실측 STL 기반**이라, 시뮬레이션 자세가 곧 실물 자세에 대응한다(아래 **§6 제어 모드**).
사진 파일을 루트 `docs/image/`에 넣으면 위 자리에 링크가 연결된다 → [docs/image 목록](../../docs/image/README.md).

---

## 1. 부품 로드

- 서버 `cad/` 폴더의 STL 목록을 `/cad/list/`로 받아 `STLLoader`로 모두 로드(단위 mm).
- 각 부품은 자기 원점 기준이라 처음엔 한 곳에 겹쳐 보인다 → 조립 모드에서 배치한다.
- 우측 **부품** 목록에서 체크박스로 표시/숨김.

## 2. 조립 모드 (부품 배치)

- 부품 클릭 → **이동/회전 기즈모**(3D 핸들) 또는 우측 **위치(mm)/회전(°) 숫자 입력**으로 배치. 숫자 화살표는 1씩.
- 결합 전 대략적인 자리/방향만 맞추면 된다(정밀 정렬은 결합이 담당).
- **고정 그룹 통째 이동:** 결합을 "고정"한 부품들은 하나의 강체로 묶여, 조립 모드에서 한 부품만 잡아 끌어도 그룹 전체가 같이 이동·회전한다(내부 결합 중심선도 동행).

## 3. 결합 모드 (면대면 관절) — CATIA 방식

두 부품을 **공유 원통축(동심) + 맞닿는 평면(면일치)** 으로 결합한다. 우측 4개 슬롯을 채우고 **결합 실행**:

| 슬롯 | 클릭 대상 |
|---|---|
| 원통 A / 원통 B | 두 부품에서 **맞물릴 원통면** (축 정렬용) |
| 평면 A / 평면 B | 두 부품에서 **맞닿을 평면** (깊이 정렬용) |

- **가상 원통 인식:** 원통면을 클릭하면, 클릭한 **원통 하나 전체**를 영역성장으로 잡는다. 조건 = "부드럽게 연결 + 법선이 축에 수직". 끝면/평면은 자동 제외되고, **축이 꺾이면(ㄱ·ㄷ 형태의 다른 원통) 자동으로 분리**된다. 잡힌 면은 반투명 색(A=초록, B=주황)으로 표시.
- **결합 수학:** ① 동심(B의 축을 A의 축에 정렬) → ② 축 일직선(수직 오프셋 제거) → ③ 면일치(평면이 만나도록 축 따라 이동).
- **종류:** **회전(revolute)** = 관절 / **고정(fixed)** = 강체 결합.

### 결합(관절) 편집기
결합 목록에서 항목 선택 시:
- **각도°** min/max — 소프트웨어 관절 한계.
- **모터** channel · us0(0°µs) · us180(180°µs) — 각도→펄스 변환 파라미터(관절별 실측값 입력, → [1_servo_calibration.md](../../arduino/docs/1_servo_calibration.md)).
- **위치보정 X/Y/Z** — 결합 후 부품(과 하위 트리)을 축 방향뿐 아니라 **자유롭게 미세 이동**. 이때 **중심선(pivot)도 함께 이동**해 회전축이 부품을 따라간다.
- **roll°** — 공유 축을 기준으로 회전.
- **🔒 고정** — 이 결합을 강체로 잠금(조립 모드에서 통째 이동 대상). 잠긴 부품 사이는 **시안색 연결선**으로 표시.
- **테스트 회전 슬라이더** — 3D에서 관절을 미리 돌려봄(중립 90°).

## 4. 저장 / 불러오기

- **저장**: 부품 위치/회전/표시 + 모든 결합(부모·자식·종류·pivot·axis·각도범위·offset·roll·locked·motor)을 `cad/assembly.json`에 저장(`/arm3d/save/`).
- **불러오기**: 페이지 로드시 `/arm3d/load/`로 복원. 저장 시 관절은 **중립(90°)** 으로 정규화되어 저장된다.
- 라운드트립(저장→불러오기) 무손실 검증 완료.

## 5. 계층/리깅 (rebuild)

- 결합 관계로 부모→자식 트리를 만들고, 회전 결합마다 **pivot 그룹**을 중심선 위치에 생성한다.
- `applyAngles()` 가 각 회전 결합의 pivot 그룹을 `axis` 기준 `(angle-90)°` 회전 → 3D 관절 구동.
- 평면화(`worldRoot.attach`) 시 부품 scale을 1로 리셋·쿼터니언 정규화 → **결합 반복해도 크기가 작아지지 않음**(부동소수 누적 방지).

## 6. 제어 모드 — 실물 ↔ 3D 연동

> 시뮬레이션으로 동작을 미리 보고, **연동을 켜면 3D와 실물이 동시에** 움직인다. **3D → 실물 단방향**(서보 피드백 없음, 3D가 기준).

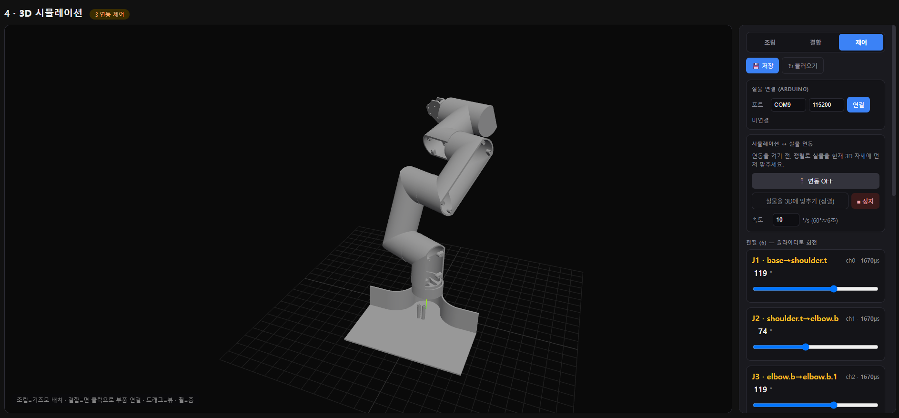
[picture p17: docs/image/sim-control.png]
제어 모드 — 좌측 3D 로봇팔, 우측 패널의 연결·연동 토글·정렬·속도·관절 슬라이더


1. **실물 연결** — 포트(기본 COM9)·보레이트(115200) 입력 → 연결. (`/arm/connect/`)
2. **관절 슬라이더 J1~J6** — 슬라이더는 **목표각**만 정하고, 램프가 천천히 이동시킨다(아래 속도 제한).
3. **정렬** — 실물 명령각을 현재 3D 자세로 **같은 속도로 천천히** 이동(라이브 전 정렬용).
4. **연동 ON/OFF** — 기본 OFF. ON일 때만 슬라이더가 실물을 구동(바뀐 펄스만 ~50ms 간격 전송).
5. **정지** — 연동 즉시 OFF + 목표를 현재 위치로 고정(그 자리에서 멈춤).
6. **속도(°/s)** — 기본 **10°/s = 60°에 6초**. 정렬·연동 모두 이 속도로 이동.

### 속도 제한 (2단 램프)
- **3D 표시각** → 슬라이더 목표로 이동, **실물 명령각** → 3D 표시각으로 같은 속도로 따라감(펄스는 명령각 기준).
- 서보 위치 피드백이 없어 "마지막 명령각"을 실물 위치 기준으로 사용 → 시작 시 실물을 3D 휴식 자세에 두면 첫 정렬부터 자연스럽다.

### 자동 재연결
- 서보 전류 브라운아웃/USB 글리치로 연결이 끊기면, 서버가 **자동으로 2초마다 재연결**(수동 버튼 불필요). 끊김 시 화면에 "⟳ 재연결 중…", 복구되면 현재 자세로 자동 정렬.
- `write_timeout`로 쓰기가 막혀도 서버가 멎지 않음.

### 각도 → 펄스 변환 (노트북이 담당)
```
us = us0 + ((180 − angle) / 180) × (us180 − us0)   # 시뮬↔실물 방향이 반대라 항상 미러
```
> angle 은 [min,max]로 클램프. 아두이노로는 기존 테스트 펌웨어 명령 **`u <channel> <us>`** 를 그대로 전송 → **펌웨어 수정 불필요**.

---

## 7. 결합(관절) 데이터 모델 (`assembly.json` 의 mate)

```jsonc
{
  "parent": "elbow.b.stl", "child": "wrist.b.stl",
  "type": "rev",                 // 'rev'(회전) | 'fix'(고정)
  "pivot": [x,y,z], "axis": [x,y,z],   // 회전 중심선(월드)
  "angle": 90, "min": 0, "max": 180,
  "offset": [0,0,0], "roll": 0,  // 위치 미세보정
  "locked": false,               // 강체 잠금
  "motor": { "channel": 3, "us0": 690, "us180": 2800 }  // 각도→펄스
}
```

## 8. 관련 파일 / 엔드포인트

| 구분 | 위치 |
|---|---|
| 프런트(전체 로직) | `armvision/templates/armvision/arm3d.html` |
| STL 서빙 | `/cad/list/`, `/cad/<name>` |
| 조립 저장/불러오기 | `/arm3d/save/`, `/arm3d/load/` → `cad/assembly.json` |
| 시리얼 브리지 | `armvision/arduino_bridge.py` (pyserial) |
| 실물 제어 API | `/arm/status/`, `/arm/connect/`, `/arm/disconnect/`, `/arm/move/` |

---

## 9. 안전 검증 — 충돌 감지 · C-space · 능동학습 (제어 모드)

디지털 트윈을 **안전 사전검증**에 쓰는 기능을 제어 모드에 내장했다. 원리·결과·그림은 **[6_digital_twin_safety.md](6_digital_twin_safety.md)** 에 상세히 있고, 여기서는 시뮬레이터 UI만 정리한다.

| UI (제어 모드) | 동작 |
|---|---|
| **충돌 HUD**(우상단) | 매 프레임 STL 정점 vs 바닥(y=0)·그리퍼 vs 비인접 링크 검사 → `바닥 여유 mm · 안전/위험/충돌` + 충돌점 마커. `충돌` 토글. |
| **🗺 격자(J2·J3·J4)** | 전 조합(5°)을 시뮬에서 회전·충돌기록 → `cspace_grid.csv` (히트맵용) |
| **🎲 랜덤(J2~J6)** | N개 무작위 자세 충돌기록 → `cspace_rand.csv` (고차원 학습용, J1은 충돌 불변→고정) |
| **🏷 질의 라벨링(CSV)** | Python(`cspace_active_loop.py`)이 고른 불확실 자세 `cspace_query.csv`를 업로드 → 시뮬로 라벨 → `cspace_labeled.csv` (능동학습 루프) |

- **안전 마진**은 콜드스타트로 측정한 **sim-real gap(30mm)** 에 연동 → "시뮬 안전 ⇒ 실물 안전" 보증. ([5_coldstart_procedure.md](5_coldstart_procedure.md))
- 이 데이터로 학습한 **충돌예측 모델(0.8µs/질의)** 이 AI 명령의 **안전 검증층** 역할 — LLM 할루시네이션을 실물 실행 전에 차단.
- 충돌 코어(`_collideOnce`)를 HUD·스윕·라벨링이 공유해 일관성 보장.

---

## 10. 알려진 한계 / 다음

- **유격**: 면 피팅 오차로 결합부에 미세 유격. 위치보정(XYZ/roll)으로 보정 가능.
- **경계 결합 pivot**: 고정 그룹과 *바깥* 부품을 잇는 결합의 pivot은 통째 이동 시 자동 갱신하지 않음(그룹 내부만). 리깅 단계에서 정리.
- **단방향 연동**: 실물 서보에 위치 피드백이 없어 3D→실물만. (마커 추적으로 보정은 [15_aruco_markers.md](15_aruco_markers.md) 단계 ⑥에서)
- **실물 테스트 체크**: 관절별 채널·us0/us180 실측값 입력 확인, 첫 구동은 모터 1개씩·좁은 가동범위로.
- **다음**: 자연어/AI(Gemma) 명령 → 관절각 목표 → 이 슬라이더 경로로 구동(3페이지 통합).

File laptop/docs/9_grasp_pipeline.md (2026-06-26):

# 물체 파지 파이프라인 — FK 샘플링 기반 파지 DB · 6DOF IK · 방향 조건부 도달영역

> **요지:** 정밀 DH 해석적 IK 대신, **보정된 디지털 트윈(arm3d)으로 그리퍼 자세를 샘플링**해
> "관절각 ↔ 그리퍼 TCP 포즈(위치+방향) ↔ 충돌" 데이터베이스를 만들고, 이를 역으로 풀어
> **물체 위치 + 접근 방향(수직/수평) → 충돌 없는 관절각**을 얻는다. 같은 위치라도 접근 방향마다
> 도달 가능 여부가 다르므로(**capability map**), AI가 명령할 때 접근 전략 자체를 데이터로 결정한다.

관련: [6_digital_twin_safety.md](6_digital_twin_safety.md) · [8_arm3d_simulator.md](8_arm3d_simulator.md) · [3_coordinate_3d_pipeline.md](3_coordinate_3d_pipeline.md)

---

## 1. 전체 구조 — 이미 가진 것 위에 얹는 "도달·파지 층(L1.5)"

```
인식(스테레오→3D좌표, 로봇 기준)  ──┐
                                    ├─▶ capability map: 이 위치에서 수직/수평 가능?
파지 DB(FK 샘플링, arm3d)  ─────────┘            │ 접근 선택
   │                                             ▼
   └─▶ 6DOF IK: (물체 위치 + 접근 자세) → 관절각  ──▶ 경로계획(접근→하강→파지→들기)
                                                        │ 충돌검증(C-space)
                                                        ▼  아두이노
```

기존 자산을 그대로 재사용한다: **arm3d 보정 FK + 충돌코어 `_collideOnce` + sim-real 마진(바닥 30mm)**.
C-space 충돌맵과 달리 파지에선 **J1(방위각)을 포함**한다.

| 역할 | 관절 | 결정 |
|---|---|---|
| 방위각(물체 방향) | J1 | ≈ atan2(obj_y, obj_x) |
| 도달 거리·높이 | J2·J3 | 수직평면 도달 |
| 그리퍼 방향(수직/수평) | J4·J5·J6 | 손목 자세 |

---

## 2. 그리퍼 TCP(파지 중앙점) 정의 — P0

그리퍼가 물체를 잡는 **기준점(TCP)** 과 그 **좌표 프레임**을 정의한다 (`arm3d.html`).

- **수동 지정:** 기준 STL 부품 선택 → XYZ 위치 + RXYZ 회전 미세조정 → ✓확정. 부품 **로컬좌표로 저장**(`localStorage armTCP_v1`)되어 관절 따라 정확히 이동.
- **강체 프레임(핵심):** 확정 순간의 프레임 방향을 **부품 로컬 쿼터니언(lq)으로 구워서** 저장 → `프레임 = 부품 현재자세 × lq` → 그리퍼가 회전해도 좌표축이 **강체로 정확히 따라감**(모든 각도 일관, 0/90/180 샘플링 불필요).
- **표시:** 시안 마커(파지점) + 3축 triad(z=파랑=접근축). 손목 회전 시 축이 그리퍼를 따라 회전.
- 자동 추정 모드(손가락 끝 군집 중심)도 있으나, **수동 확정 권장**.

---

## 3. 관절 회전축 보정 — 리깅 정확화 (FK 토대)

자동 면결합으로 잡은 **회전축(`m.axis`)·피벗(`m.pivot`)** 의 작은 오차가 관절 회전 시 **비틀림으로 증폭·누적**되어 그리퍼/TCP가 틀어진다. 부품은 강체로 붙어 슬립은 없고, **축 오차가 유일한 원인**.

관절 편집(결합 모드)에 추가된 보정 도구:

| 도구 | 역할 |
|---|---|
| 위치보정(aox/y/z) | 부품 서브트리 이동 |
| roll° | 축 둘레 롤 |
| **축기울기** X/Y/Z | 회전축 **방향** 미세회전(비틀림 제거) |
| **축위치** X/Y/Z | 회전중심(피벗) **이동**(궤도 정렬) |

→ 관절당 **위치+롤+축방향+축위치 = 6DOF 완전 보정**. **선택 관절의 회전축을 크게 시각화**(z=파랑 triad + 노란 축선 ±240)하여 눈으로 보며 조정. **끝각(0/180°)에서** 비틀림이 최소가 되게 맞추고 💾 저장(축 무관한 휴식 90°에선 효과 없음).

> 정확한 축 → FK·C-space·파지 데이터·TCP가 모두 정밀해진다. (향후 콜드스타트 screw axis로 자동화 가능.)

---

## 4. 파지 데이터셋 — P1 (FK 샘플링)

4페이지 **파지 스윕(J1~J6)** 버튼: 관절을 무작위로 쓸어 각 자세를 기록 → `grasp_dataset.csv`.

> 🎬 데모 영상 — 파지 데이터셋 생성: [①](https://drive.google.com/file/d/1aMuK7l9k4ZoUPRI2btJ8vOeubB9G_r45/view?usp=sharing) · [②](https://drive.google.com/file/d/18LRvhoQJ6_2y2a_KH3mV3oGGfNr9pnhw/view?usp=sharing)

| 컬럼 | 의미 |
|---|---|
| `J1`~`J6` | 관절각 |
| `tcp_x,y,z` | 그리퍼 TCP 위치(mm, y가 위) |
| `app_x,y,z` | 접근 단위벡터 = 프레임 z (수직 app_y≈−1, 수평 |app_y|≈0) |
| `qx,qy,qz,qw` | **그리퍼 프레임 전체 자세(쿼터니언)** — 6DOF IK용 |
| `floor_clear_mm` / `self_clear_mm` | 바닥/자기 충돌 여유 |
| `collision` | 1 = 충돌(잡기 후보 아님) |

`_collideOnce`·`_csDownload` 재사용으로 **sim-real 일관성** 유지. 10만 샘플 권장(충돌 ~9%).
> 회전 오프셋·강체 프레임을 바꾸면 **재스윕**해야 데이터가 일치한다.

---

## 5. 도달영역 분석 — `calibration/grasp_analysis.py`

`grasp_dataset.csv` → 충돌 없는 TCP 점군의 3D 산점(파지방향별 색) + 높이별 X-Z 도달영역.

```
python calibration/grasp_analysis.py <csv>
  → docs/image/grasp-reach3d.png, grasp-reach-top.png
```

**100k 실측:** 충돌 없음 91.3%, 작업공간 반구형(X[−415,384] Y[16,527] Z[−407,406]).
**IK 최근접 잔차**(밀도 척도): 전체 중앙 **5.4mm**, 수직 8.8 / 수평 7.5mm → sim-real 마진 안.

---

## 6. 6DOF 파지 IK — P2 (시뮬 내 인터랙티브)

4페이지 **파지 IK** 카드: 목표(물체) **프레임**(위치 + 접근 자세) → 데이터셋에서 가장 가까운 충돌 없는 관절각을 찾아 팔 이동.

- **목표 = 좌표 프레임**(주황): XYZ 이동(버튼/입력) + **수직↓/수평→ 프리셋** + **RX/RY/RZ** 회전
- **매칭:** 6DOF 데이터(쿼터니언)면 **목표 프레임 전체와 매칭**(45° 이내) → roll까지 맞춰 **의도한 접근 자세**로 잡음. 구버전 CSV(접근축만)는 폴백.
- **결과:** `위치 잔차 mm · 자세 오차 ° · 관절각`. 위치 45mm 초과 = 도달 어려움.
- 자동 모드: 목표를 옮기면 관절이 실시간 추종.

> **교훈:** 위치만 맞추면 손목이 아무렇게나 꺾인 자세도 통과한다(예: J4=149,J5=155). 깔끔한 파지(예: J4=0,J5=0,J6=90)는 **전체 자세 매칭**이 필요 → 데이터셋에 쿼터니언 기록.

---

## 7. 방향 조건부 도달영역(capability map) — `calibration/grasp_reachability.py`

**같은 위치라도 수직으로 잡을 수 있는 영역과 수평으로 잡을 수 있는 영역이 다르다.** 이를 복셀로 정량화.

```
python calibration/grasp_reachability.py <csv> [voxel_mm=35] [minN=2]
  → docs/image/grasp-capability3d.png (수직만/수평만/둘다) + grasp_capability.json
python calibration/grasp_reachability.py <csv> --query X Y Z [r=45]   # 그 위치 가능 접근
```

**100k 실측:** 수직만 312 · 수평만 854 · 둘다 2466 복셀 → 접근 가능성이 **위치 의존**임을 입증.
런타임 조회는 **반경 스캔**(복셀 가장자리 과엄격 회피). 예) `(−115,120,−400)` → 수직(11)·수평(18) 둘 다 가능, 최근접 11mm.

---

## 8. AI 명령 → 접근 전략 결정 흐름 (목표 통합)

```
AI(VLM): 물체 인식 + 3D좌표 + 모양기반 선호(납작→수직 / 길쭉→수평)
   → 노트북: capability map 조회 — 이 위치 수직? 수평? 가능?
       · 선호 가능 → 그대로  · 선호 불가·다른쪽 가능 → 전환(통보)  · 둘 다 불가 → 미도달 보고
   → 6DOF IK: 선택 접근의 파지 자세(관절각)
   → 경로계획(P4): 프리그래스프(접근축으로 떨어진 곳, 그리퍼 열림) → 직진 → 닫기 → 들기  [충돌검증]
   → 아두이노
```

capability map = **AI의 접근 타당성 검증층**(C-space 충돌검증층과 같은 역할 — 불가능한 파지 명령 차단).

---

## 9. 데이터·산출물

| 파일 | 내용 |
|---|---|
| `grasp_dataset.csv` | 파지 스윕 결과(관절·TCP포즈·쿼터니언·충돌) |
| `calibration/grasp_analysis.py` | 도달영역 3D 그래프 |
| `calibration/grasp_reachability.py` | 방향별 capability map + 조회 |
| `calibration/grasp_capability.json` | 복셀별 수직/수평 가능여부(런타임 조회) |
| `armvision/templates/armvision/arm3d.html` | TCP 정의·축보정·스윕·IK UI |
| `localStorage armTCP_v1` | 확정된 TCP(부품·로컬위치·회전·강체 쿼터니언) |

---

## 10. 다음 단계

1. **전 관절 축 보정** → 정확한 FK
2. **6DOF 재스윕(10만)** → 쿼터니언 포함 정확 데이터 → capability map 재생성
3. **P4 경로계획** — capability 조회 → 접근 선택 → IK → 접근 동작 시퀀스 → C-space 충돌검증
4. **P3 능동학습**(선택) — 미도달·경계 영역 샘플 보강
5. **AI 서버 연동** — VLM 접근 선호 ↔ capability map 타당성 검증 → DSL → 노트북 실행

> 작업 방식: 작은 단위로 시뮬에서 검증하며 진행. 데이터는 2026-06 실측 기준, 환경(조립·보정) 변경 시 재스윕.

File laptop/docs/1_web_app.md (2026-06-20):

# 노트북 웹앱 (Django) — 기능 명세

> 노트북 제어 허브의 **웹 UI**. 비전·캘리브레이션·로봇 제어를 브라우저에서 다룬다.
> 프로젝트 `config`, 앱 `armvision`. `python manage.py runserver` → http://127.0.0.1:8000/
> 상단 네비게이션으로 4개 페이지 이동.

---

## 페이지 구성 (4개)

### 1 · 카메라 · 탐지  `/`

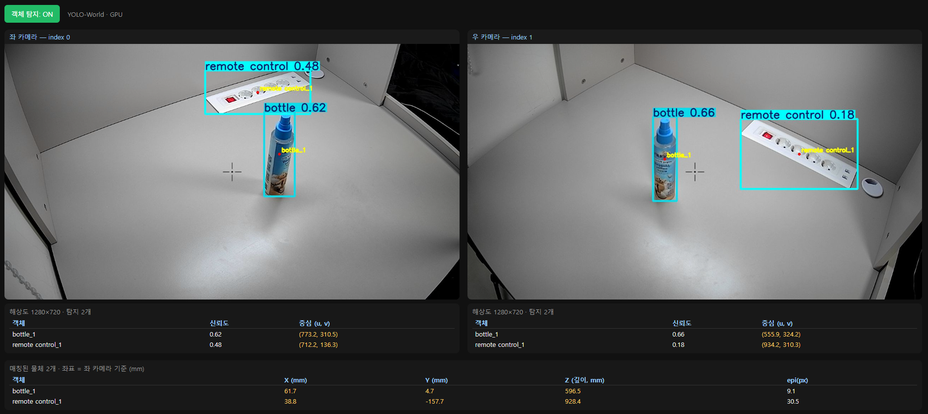
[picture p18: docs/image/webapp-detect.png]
1페이지 — 좌·우 카메라 YOLO-World 탐지(remote control·bottle) + 2D/3D 좌표표


- **좌/우 카메라 선택** — **🔄 카메라 스캔**으로 노트북의 카메라를 찾아(가능하면 장치 이름까지) 드롭다운에서 좌·우를 고른다. 선택은 서버에 저장(`armvision/cam_config.json`)되어 탐지·스테레오·캘리브레이션에 **공통 적용**. USB 재연결로 인덱스가 바뀌어도 다시 고르면 됨.
  - 장치 목록은 **pygrabber**(DirectShow)로 카메라를 열지 않고 읽는다 → 여러 웹캠 동시 점유로 일부를 놓치는 문제 없음. 없으면 인덱스 직접 탐색으로 폴백.
  - **주의:** 같은 모델 웹캠이 index 0·2처럼 **중복 enumerate** 될 수 있음(같은 물리 장치). 둘을 동시에 좌/우로 쓰면 한쪽이 검은 화면 → 서로 다른 장치를 고를 것.
- 선택한 2대 **MJPEG 실시간** 표시, 화면 중앙 **십자선**. 카메라 스레드는 **자가 치유**(점유가 풀리면 자동 재오픈).
- **객체 탐지 토글** — YOLO-World(GPU). 박스 + 중심점 + **객체 id(`class_n`, 좌→우)**.
- **2D 좌표표**(카메라별, 1초 갱신): 객체 id · 신뢰도 · 중심(u,v).
- **3D 좌표표**: 캘리브레이션 완료 시 **자동 활성** — 좌·우 매칭·삼각측량한 (X,Y,Z) mm.

### 2 · 캘리브레이션 위저드  `/setup/`
6단계 인터랙티브. **카메라 먼저 고정·보정 → 로봇 설치**( ①②③ → 로봇 → ④⑤⑥ ).
좌/우 카메라는 **1페이지에서 선택한 설정(`cam_config.json`)을 그대로 사용** — 화면·코너수·촬영·캘리브레이션 모두 동일 카메라.
1. **ChArUco 촬영** — 양 카메라 코너 오버레이 + 캡처(좌·우 동시) + 실시간 코너 수. ✅ 동작
2. **카메라 캘리브레이션** — 내부 K·왜곡 + 스테레오 R·T 산출, 결과 표시. ✅ 동작
3. **3D 검증** — 보드 30mm 복원 오차/스케일. ✅ 동작
4. **로봇 배치 & 베이스 마커** — 골격(마커 부착 후 구현)
5. **카메라→로봇 변환 T** — 골격
6. **관절 위치 & 작업공간** — 골격
- 절차 상세: [14_setup_procedure.md](14_setup_procedure.md), 파이프라인: [3_coordinate_3d_pipeline.md](3_coordinate_3d_pipeline.md)

### 3 · 자연어 제어  `/control/`
- 한국어 명령으로 로봇팔 구동하는 화면. **현재 골격(채팅 UI)만.**
- AI 서버(Whisper·Gemma) 완료 후 **노트북·아두이노·AI 서버 통합 단계**에서 gRPC 클라이언트 + DSL 실행기와 연결.

### 4 · 3D 시뮬레이터 & 실물 연동  `/arm3d/`
- **Three.js** 기반. 팀원 **STL 부품을 직접 조립**해 디지털 트윈을 만들고 **실물과 동시 구동**. 세 모드:
  - **조립** — 기즈모/숫자로 부품 배치. 고정 그룹은 통째 이동.
  - **결합** — CATIA식 **면대면(원통 동심 + 평면 일치)** 으로 회전/고정 관절 정의. 가상 원통 자동 인식. 관절별 모터 매핑·위치보정·고정.
  - **제어** — 관절 슬라이더로 3D 구동 + **연동 ON 시 실물 서보 동시 구동**(정렬 후 라이브, ~30ms 실시간 전송). 각도→펄스는 노트북이 변환, 아두이노엔 `u ch us` 전송(펌웨어 수정 불필요).
- 조립 결과는 `cad/assembly.json`에 저장/복원. **6관절 리깅 완료, AI 연동 직전 단계.**
- 상세: **[8_arm3d_simulator.md](8_arm3d_simulator.md)**

---

## 주요 엔드포인트

| 경로 | 용도 |
|---|---|
| `/video_feed/?cam=&detect=&charuco=` | MJPEG 스트림 (탐지/ChArUco 오버레이) |
| `/detections/?cam=` | 카메라별 2D 탐지 JSON |
| `/positions3d/` | 좌·우 매칭·삼각측량 3D JSON |
| `/cameras/` · `/cameras/config/` | 카메라 목록 / 좌·우 선택 저장 |
| `/setup/capture/` · `/setup/run_calibration/` · `/setup/run_validation/` · `/setup/state/` · `/setup/charuco_status/` | 위저드 백엔드 |
| `/cad/list/` · `/cad/<name>` | STL 목록 / 파일 서빙 |
| `/arm3d/load/` · `/arm3d/save/` | 조립(`cad/assembly.json`) 불러오기/저장 |
| `/arm/status/` · `/arm/connect/` · `/arm/disconnect/` · `/arm/move/` | 실물 로봇팔 시리얼 연동 |

---

## 모듈

| 파일 | 역할 |
|---|---|
| `armvision/camera.py` | 카메라 공유 스레드(자가치유) + MJPEG + 십자선 + 카메라 목록/선택(`cam_config.json`) |
| `armvision/detector.py` | YOLO-World 탐지 + 객체 id |
| `armvision/charuco.py` | ChArUco 검출/오버레이 (DICT_5X5_100, 6×8, 30/23mm) |
| `armvision/stereo3d.py` | 좌·우 매칭 + 삼각측량 3D (지연 로딩) |
| `armvision/arduino_bridge.py` | 실물 로봇팔 시리얼(pyserial, COM9) — 펄스 전송 |
| `armvision/views.py`, `templates/` | 페이지·엔드포인트 |
| `calibration/calibrate_stereo.py`, `validate_triangulation.py` | 캘리브레이션·검증 |
| `calibration/make_targets.py`, `make_arm_markers.py` | 인쇄용 ChArUco/ArUco PDF |

> 의존성: `ultralytics`(YOLO-World)·`opencv-python`·`pyserial`·`pygrabber`(카메라 이름), torch(CUDA).

---

## 구현 완료 / 예정

**완료**
- ✅ **STL 기반 3D 시뮬레이터**(4페이지): 조립·면대면 결합·6관절 리깅·저장. → [8_arm3d_simulator.md](8_arm3d_simulator.md)
- ✅ **실물 연동**(`arduino_bridge.py`): 시리얼 연결 + **각도→펄스 변환**(관절별 실측, [../../arduino/docs/1_servo_calibration.md](../../arduino/docs/1_servo_calibration.md)) + 전송 → 4페이지 슬라이더가 **3D+실물 동시** 구동.
- ✅ **카메라 선택**(1페이지): 좌/우 카메라를 노트북 장치에서 선택·저장.

**예정**
- **단계 ⑤⑥**: 베이스/추적 ArUco 마커로 카메라→로봇 변환 T, 관절 추적([15_aruco_markers.md](15_aruco_markers.md)).
- **3페이지 통합**: AI 서버(Whisper·Gemma) → gRPC + DSL 실행기 → 4페이지 연동 경로로 구동.
- **이진 프로토콜**: 현재 ASCII `u ch us` → CommandPacket+CRC([../../docs/4_serial_protocol.md](../../docs/4_serial_protocol.md)).

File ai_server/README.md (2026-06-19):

# ai_server/ — AI 추론 서버

> **3계층 중 Layer 3 — "무엇을 할지" 결정.**
> 음성·이미지·자연어를 이해해 로봇이 수행할 **의도(JSON DSL)** 를 만든다. (MSI EdgeXpert에서 구동 예정)

전체 구조에서 이 폴더의 위치 → [공통 docs/1_architecture.md](../docs/1_architecture.md)

---

## 이 폴더가 하는 일 (예정)

- **Whisper Large-v3** — 한국어 음성 → 텍스트(STT)
- **Gemma 4** — 멀티모달 LLM/VLM: 명령 이해 + 객체 의미 추론(색·매칭)
- **Qwen3-Embedding-8B + FAISS** — RAG로 환각 차단, 캘리브레이션/지식 검색
- 결과를 **gRPC + Protobuf**로 노트북에 전달 → [../docs/3_grpc_interface.md](../docs/3_grpc_interface.md)

> **현황(2026-06-14):** 음성 → Whisper STT → **Gemma 4 31B** → JSON DSL → 검증 **end-to-end 작동**(실제 마이크 음성 확인, 할루시네이션 방지 입증). gRPC·비전·RAG는 다음 단계.

자세히 → 설계 [docs/README.md](docs/README.md) · **구현 명세 [docs/1_implementation.md](docs/1_implementation.md)**

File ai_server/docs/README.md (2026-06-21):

# AI 서버 (MSI EdgeXpert) — 기능 명세

> **역할: "무엇을 할지" 결정.** 음성·영상을 받아 의미를 추론하고, 노트북이 실행할 JSON DSL을 생성한다.
> 결정적·실시간 작업(탐지·삼각측량·IK·안전)은 노트북 책임이며 여기서 하지 않는다.
> 인터페이스: [gRPC 명세](../../docs/3_grpc_interface.md) · 출력 형식: [DSL 명세](../../docs/5_dsl_spec.md)

### 세부 문서
| 문서 | 내용 |
|---|---|
| [1_implementation.md](1_implementation.md) | 구현 명세 — 음성/텍스트(+이미지)→STT→Gemma 4(VLM/DSL)→검증→노트북, warm gRPC |
| [2_grasp_place_integration.md](2_grasp_place_integration.md) | **파지·놓기 연동** — 상위 `pick`/`place` DSL로 통일·검증·노트북 MLP 런타임 매핑(책임 분리) |

---

## 1. 하드웨어 / 환경

| 항목 | 값 |
|---|-----|
| 디바이스 | MSI EdgeXpert |
| 칩셋 | GB10 Grace Blackwell |
| 메모리 | 128GB unified |
| 언어 | Python 3.11 |
| 통신 | gRPC 서버 (포트 50051) |

---

## 2. 구성 모델

| 모델 | 역할 | 입력 → 출력 |
|---|---|---|
| Whisper Large-v3 | 한국어 STT | WAV → 텍스트 |
| Gemma 4 (멀티모달) | LLM 추론 + VLM | 텍스트+이미지+탐지결과 → JSON DSL |
| Qwen3-Embedding-8B | RAG 임베딩 | 텍스트 → 8192-dim 벡터 |
| FAISS | 벡터 검색 | 벡터 → 유사 지식 |

---

## 3. 기능 책임

1. **STT** — 음성(WAV)을 한국어 텍스트로 변환.
2. **객체 매칭 (VLM)** — "빨간 컵" 같은 자연어를 노트북이 보낸 탐지 객체와 매칭.
3. **속성 인식** — 색·재질·크기 등 시각 속성 추론.
4. **의도 파싱** — 사용자 명령을 단계별 동작 의도로 분해 (Chain-of-Thought).
5. **DSL 생성** — 화이트리스트 op만으로 구성된 JSON DSL 출력.
6. **RAG grounding** — 워크스페이스·관절 한계·페이로드·객체 무게 등 검증된 수치를 컨텍스트로 주입해 환각 차단.

---

## 4. 추론 절차 (Chain-of-Thought)

```
1. 명령 이해      — 무슨 동작을 원하는지
2. 객체 매칭      — 시각 데이터의 어떤 객체인지
3. 제약 검증      — 무게·도달 가능성·안전
4. 동작 계획      — 단계별 op 시퀀스
5. JSON DSL 출력
```

안전 규칙: 페이로드 초과·작업공간 외·모호한 명령은 `ask_user`로 거부/질의.
(최종 안전 보장은 노트북의 4단계 검증 + 실시간 모니터.)

---

## 5. RAG 컨텍스트 주입

콜드스타트 캘리브레이션 결과가 FAISS에 저장되어 있으며, DSL 생성 시 다음을 동적 주입:
`max_payload_g`, `workspace`, `joint_limits`, `detected_objects`, `object_weights`.

지식 베이스 스키마는 [2_system_spec.md §7](../../docs/2_system_spec.md) 참조.

---

## 6. 예정 코드 구조 (구현 단계)

```
ai_server/
├── pyproject.toml
├── src/
│   ├── main.py                 # gRPC 서버 진입점
│   ├── grpc_handler.py
│   ├── inference/
│   │   ├── whisper_stt.py
│   │   ├── gemma_llm.py
│   │   └── gemma_vlm.py
│   ├── rag/
│   │   ├── qwen_embedding.py
│   │   ├── faiss_index.py
│   │   └── knowledge_base.py
│   └── prompts/
│       ├── system_prompt.txt
│       └── examples.json
└── tests/
```

---

## 7. 단독 검증 항목 (하드웨어 없이 가능)

- [ ] EdgeXpert에서 Whisper Large-v3 한국어 STT 구동 확인
- [ ] Gemma 4 멀티모달 모델 로드 및 추론 구동 확인
- [ ] Qwen3-Embedding 임베딩 + FAISS 인덱싱 파이프라인
- [ ] 샘플 입력 → JSON DSL 생성 및 스키마 적합성 확인

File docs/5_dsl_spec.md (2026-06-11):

# JSON DSL 명세 — 명령 표현 언어

> **공통 합의 문서.** AI 서버(Gemma)는 이 DSL만 생성하고, 노트북은 이 DSL만 실행한다.
> `exec`/`eval` 등 임의 코드 실행은 **금지**. 사전 정의된 화이트리스트 op만 호출 가능.
> 설계 패러다임: Code-as-Policies (LLM이 제한된 DSL을 직접 생성).

---

## 1. op 카탈로그 (화이트리스트)

```python
ALLOWED_OPS = {
    "move_above":         handle_move_above,
    "descend_and_grasp":  handle_descend_and_grasp,
    "lift":               handle_lift,
    "move_to":            handle_move_to,
    "release":            handle_release,
    "return_home":        handle_return_home,
    "ask_user":           handle_ask_user,
}
```

| op | 파라미터 | 동작 |
|----|---|---|
| `move_above` | `target`, `height_mm` | 객체 위 height_mm 위치로 이동 |
| `descend_and_grasp` | `target` | ToF 폐루프로 정밀 하강 + 그립 |
| `lift` | `height_mm` | 현재 위치에서 수직 상승 |
| `move_to` | `target`, `offset[3]` | 객체 위치 + offset으로 이동 |
| `release` | (없음) | 그리퍼 열기 |
| `return_home` | (없음) | 홈 포지션 복귀 |
| `ask_user` | `question` | 모호한 경우 사용자에게 질문 |

---

## 2. 스키마

```json
{
  "reasoning": "string (Chain-of-Thought 추론 과정)",
  "actions": [
    { "op": "move_above", "target": "cup_2", "height_mm": 100 },
    { "op": "descend_and_grasp", "target": "cup_2" },
    { "op": "lift", "height_mm": 100 },
    { "op": "move_to", "target": "book_1", "offset": [50, 0, 0] },
    { "op": "release" },
    { "op": "return_home" }
  ]
}
```

- `target`은 좌표가 아니라 **노트북이 탐지한 객체 ID**다. 좌표 해석은 노트북 책임.
- 모든 길이 단위는 mm.

---

## 3. 노트북의 4단계 검증

AI 서버 출력은 신뢰하지 않는다. 노트북은 실행 전 다음을 반드시 통과시킨다.

```python
def validate_dsl(script):
    # 1. 스키마 검증 (JSON 구조)
    if not matches_schema(script):
        return reject("스키마 오류")

    # 2. op 화이트리스트 검증
    for action in script['actions']:
        if action['op'] not in ALLOWED_OPS:
            return reject(f"unknown op: {action['op']}")

    # 3. 파라미터 안전 범위 (워크스페이스, 관절 한계, 페이로드)
    for action in script['actions']:
        if not validate_action_parameters(action):
            return reject(f"위험한 파라미터: {action}")

    # 4. 시퀀스 논리 검증 (예: grasp 없이 release, 도달 불가 등)
    if not validate_sequence_logic(script['actions']):
        return reject("비논리적 시퀀스")

    return accept()
```

| 단계 | 검증 내용 |
|---|---|
| 1 스키마 | JSON 구조, 필수 필드 존재 |
| 2 화이트리스트 | `op`가 `ALLOWED_OPS`에 존재 |
| 3 파라미터 | 워크스페이스/관절 한계/페이로드 범위 내 |
| 4 시퀀스 논리 | 동작 순서의 물리적 타당성 |

---

## 4. 안전 규칙 (AI 서버 측 가이드)

Gemma 시스템 프롬프트에 명시:

- 페이로드 한계(150g) 초과 시 → `ask_user`로 거부
- 작업공간 외 위치 요청 → `ask_user`로 거부
- 모호한 명령 → `ask_user`로 명확화 요청
- 화이트리스트 외 op 사용 금지

> 단, AI 서버의 안전 규칙은 1차 방어선일 뿐이며 **최종 안전 보장은 노트북의 4단계 검증 + 실시간 안전 모니터**가 담당한다.

---

## 5. 컨텍스트 주입 (RAG → Gemma)

DSL 생성 시 다음 컨텍스트가 동적으로 주입된다 (값은 콜드스타트 캘리브레이션 결과를 RAG에서 조회):

```python
context = {
    "max_payload_g": 150,
    "workspace": {"x_min": -200, "x_max": 200,
                  "y_min": 50, "y_max": 350,
                  "z_min": 50, "z_max": 250},
    "joint_limits": {"J1": [-90, 90], ...},
    "detected_objects": [...],   # 노트북 YOLO-World + 삼각측량 결과
    "object_weights": {...},     # RAG object_database
}
```

---

## 6. TODO (구현 단계)

- [ ] `laptop/src/dsl/validator.py` 4단계 검증 구현
- [ ] `laptop/src/dsl/ops.py` 각 핸들러 구현
- [ ] JSON Schema 파일 정의 및 자동 검증
- [ ] AI 서버 시스템 프롬프트 ↔ 본 카탈로그 동기화 테스트

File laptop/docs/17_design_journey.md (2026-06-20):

# 17. 파지 학습·실행을 만들며 한 고민 (Design Journey)

> 📂 [루트](../../README.md) → [laptop](../README.md) → [laptop/docs](README.md) → **17 (고민 기록)**

> **이 문서의 목적.** 다른 문서들이 "무엇을 만들었나(결과)"를 명세한다면, 이 문서는 **"왜 그렇게 결정했나, 무엇이 막혔고 어떻게 풀었나"**를 시간 순서로 남긴다.
> 똑같은 고민을 반복하지 않기 위한 의사결정 로그다. 결론만 보려면 각 절의 **▶ 결정**을 읽으면 된다.

---

## 1. "물체를 잡는 법"을 어떻게 학습시킬 것인가 — Physical AI vs. C-space식 학습

**고민.** 가상의 물체를 두고 자동으로 잡게 하고 싶었다. 그런데 요즘 화제인 Physical AI(대규모 시뮬·강화학습·foundation model)를 써야 하나? 우리 장비(RTX 3050 4GB)로 가능한가?

- Physical AI/RL: 강력하지만 대규모 시뮬·GPU·sim-to-real 튜닝이 필요. 캡스톤 범위·장비를 초과.
- 우리가 이미 **디지털 트윈 C-space 충돌지도**를 신경망으로 학습한 경험([6_digital_twin_safety.md](6_digital_twin_safety.md))이 있다 — "공간을 샘플링해 라벨을 만들고 MLP로 일반화"하는 패턴.

**▶ 결정: L1 파지 학습(C-space식).** 시뮬레이터가 스스로 파지를 시도→접촉/충돌로 자동 라벨링→그 데이터로 MLP가 "이 물체를 이 접근으로 잡을 수 있나"를 일반화. 무거운 RL 없이, 우리가 잘하는 방식의 연장선. → [12_grasp_orientation_learning.md](12_grasp_orientation_learning.md), [13_grasp_learning_mlp.md](13_grasp_learning_mlp.md).

---

## 2. 무엇을 학습시킬 것인가 — 방향(수직/수평)이 핵심이었다

**고민.** 물체를 "잡을 수 있다/없다"만으로는 부족했다. 같은 컵이라도 **위에서 수직으로** 잡을지, **옆에서 수평으로** 잡을지가 물체 형상·바닥 안착 여부로 갈린다. J6 관절 각도에 따라 노란 면(파지면)이 수평이어야 수직으로 잡힌다는 걸 시각화로 확인.

**▶ 결정: 접근 조건부 학습.** 입력 특징에 `approach`(수직/수평)를 넣고, 한 물체에 대해 **두 접근 모두** 데이터를 생성. 출력은 ①파지 가능 여부(분류) ②품질(회귀) ③접근 선택(argmax). 물체는 바닥에 안착시켜 형상 효과가 반영되게.

---

## 3. 데이터가 계속 거짓말을 했다 — 라벨링 신뢰성과의 싸움

가장 길게 싸운 부분. 데이터셋이 그럴듯한데 **틀린** 라벨을 만들어내는 일이 반복됐다.

| 증상 | 진짜 원인 | 교훈 |
|---|---|---|
| 성공률 0.5%, 데이터에 perp~227mm | `applyAngles()`는 로컬 변환만 갱신, **월드 행렬 미갱신**(동기 루프엔 렌더가 없음) → 손가락이 rest pose에 멈춤 | 동기 평가 루프에선 반드시 `rigRoot.updateMatrixWorld(true)` |
| 성공률 99% (음성 샘플 거의 없음) | 양성 위주 샘플링 | 음성도 **넓게/전역** 샘플링해야 분류기가 경계를 배움 |
| 큰 물체(R150+)가 오히려 99% 성공(거꾸로) | jaw 판정이 **그리퍼 개폐 한계를 무시**, perp 임계가 R에 비례 | 실측(지름 50mm까지) → `2R ≤ glGrip` 게이트 + 고정 임계 |
| 충돌 미검출(물체가 팔 안에 있는데 유효) | 라벨링이 **물체-팔 충돌**을 안 봄 | 라벨에 충돌 검사 필수 → `_bodyHitsObject`/`_gripperHitsObject` |

**▶ 결정/교훈.** "**데이터가 곧 모델**"이다. MLP를 의심하기 전에 라벨링 시뮬을 의심하라. 특히 (a) 월드 행렬 동기화, (b) 양·음성 균형, (c) 물리 제약(개폐 폭)의 실측 반영, (d) 충돌까지 포함한 유효성 — 이 넷이 갖춰져야 데이터가 진실을 말한다. 사용자가 "grasp_dataset 자체에 문제가 있어 보인다"고 짚은 게 정확했고, P1 파지 DB를 충돌 인식으로 재생성(30만→100만)했다.

---

## 4. "유효 파지까지는 가는데 자세가 엉성하다" — 학습 한계인가 구조 한계인가

**고민.** 최적 자세 찾기로 잡으면 잘 잡을 것 같은데 수직/수평이 깔끔하지 않다. 이게 **MLP 학습의 한계**인가, 아니면 **로봇팔의 구조적 한계**인가? 이 둘을 구분 못 하면 엉뚱한 곳(데이터만 더, 또는 팔만 탓)을 고치게 된다.

**▶ 결정: 접근 가능 구역 맵(🗺)으로 구조를 먼저 본다.** 특정 크기 물체(R15·H30)로 워크스페이스 전체를 격자 스캔해 각 위치에서 수직/수평 도달 기울기를 측정·시각화. 결과는 명확했다 — **도달 영역이 환형**이고 **베이스 근접부는 수직 파지 사각지대**. 즉 일부는 **팔의 기구학적 한계**(MLP 잘못이 아님)였다.

**교훈.** 학습 모델을 디버깅하기 전에 **물리적으로 가능한 영역**을 측정하라. "할 수 있는 만큼" 정렬하고 남은 기울기를 숫자로 보여주는 방식(`tilt=angErr`)으로, 한계를 숨기지 않고 드러냈다.

---

## 5. 어떻게 접근할 것인가 — 한 번에 vs. 두 단계(standoff→직선)

**고민.** 물체로 바로 IK를 풀면 노란 면이 꺾인 채 비스듬히 들어가 측면을 치거나 밀어낸다. 사용자 제안: **jaw의 x축을 물체 축과 먼저 정렬하고, 2단계에서 그 축을 따라 똑바로 내려가자**(수평도 동일).

후보를 두 가지로 정리해 논의했다:
- (a) 한 자세로 한 번에 — 단순하지만 정렬·간섭 제어가 어려움.
- (b) **standoff에서 정렬 → 직선 접근** — 프리그래스프에서 자세를 맞추고 접근축으로만 직진. 6-DOF 파지 문헌의 표준(approach vector + pre-grasp standoff).

**▶ 결정: (b) 두 단계.** `executeGraspTwoStage`. 막히면 직접 접근으로 폴백. → [16 §2](16_grasp_place_runtime.md).

---

## 6. 잡았으면 놓아야 한다 — 놓기 프로세스와 좌표 추적

**고민.** Gemma와 연동하면 "이 물체를 저기에 놓아줘"가 된다. 그러려면 **놓기(place)**가 집기와 짝을 이뤄야 한다. 그런데 구현하니 문제가 줄줄이 나왔다.

- 물체를 옮겨도 **놓기 IK 목표 좌표가 안 움직임** → `_updateHeld`가 ikX/Y/Z를 든 물체로 갱신.
- 놓기 좌표가 xz뿐이라 **물체를 공중에** 둠 → `plY` 입력 추가.
- 운반 중 **바닥을 쓸며** 감 → 들어올림→운반→하강 4스텝 + 운반 높이 여유.

**▶ 결정.** 집기·놓기를 **한 쌍의 원자 동작**으로 설계. 물체는 닫는 순간 강체 부착(`_held`), 매 프레임 TCP를 따라가고, 놓기 좌표·높이를 명시적으로 받는다.

---

## 7. 놓을 때 물체가 기운다 — J6 자이로

**고민.** 놓기는 되는데, 보니 **J6를 충분히 돌릴 수 있는데도 덜 돌려** 운반 중 jaw(물체)가 기운다. 수평 상황에서 jaw의 xz를 유지해야 물체를 안전하게 내려놓는다.

**원인.** IK 비용이 **위치 위주**라 자세가 뒷전 → 위치만 맞추고 손목을 덜 회전.

**▶ 결정: 자세 가중치 손잡이 `ow` + 레벨링.** `_ikToPose`에 `ow`를 노출(기본 1.5), 놓기에선 `ow=4`로 자세를 강하게 유지. 접근이 수평이면 손가락축을 수직으로 재정렬(레벨링)해 노란 면을 수평으로 고정. → J6가 "충분히" 돌아 물체가 수평을 유지. → [16 §4](16_grasp_place_runtime.md).

---

## 8. 일관되게 지킨 원칙

- **작은 단위로, 하나씩 검증.** 큰 리팩터 대신 증상→원인→최소 수정→확인을 반복. (incremental fast workflow)
- **도구가 섞이면 정리부터.** 버튼/도구가 많아질 때마다 역할을 갈라 정리(🧠 주파지·🎯 단일최적·🗺 진단·📥 놓기).
- **문헌에 근거를 둔다.** 손목 roll 최적화·approach 샘플링은 GraspNet/Dex-Net 등 6-DOF 파지 생성 연구에 맞춤([13 §9](13_grasp_learning_mlp.md)).
- **한계를 숨기지 않는다.** 도달 못 하면 기울기°·거부 사유를 그대로 표시 → 사용자가 구조 한계와 버그를 구분할 수 있게.

---

## 9. 남은 고민(다음 차례)
- **AI 서버 연동.** Gemma DSL `[pick, place]` ↔ 시뮬 원자 동작. 자연어·음성에서 물체 id/목표로의 번역.
- **물체 자세 부착.** 현재는 위치만 부착 — 회전까지 들고 옮기면 더 일반적인 놓기가 된다.
- **실물 적용.** 시뮬에서 검증한 시퀀스를 실제 서보로. sim-real gap·접근 가능 구역 안에 물체 배치 전제.

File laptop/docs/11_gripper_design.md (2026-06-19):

# 그리퍼 정밀 설계 — 평행집게 개폐 시뮬레이션과 sim-to-real 신뢰성

> **요지:** 파지 데이터셋(10만 세트)이 주는 것은 "도달 가능 + 충돌 없음"인 **접근 자세**일 뿐,
> 그 자세에서 그리퍼가 **실제로 물체를 잡는지**는 보장하지 않는다. 이를 시뮬레이터에서 검증하려면
> 그리퍼의 **개폐 기구(평행집게 손가락의 병진 운동)** 를 정확히 모델링해야 한다. 그래야 손가락이
> 닫힐 때 가상 물체와 **양쪽에서 접촉(antipodal ≥2점)** 하는지 판정할 수 있고, 비로소 시뮬 파지
> 데이터를 **실물에 신뢰성 있게** 쓸 수 있다. 이 문서는 *왜* 그리퍼를 이 정도로 디테일하게 만들었는지와
> *어떻게* 구현했는지를 정리한다.

관련: [9_grasp_pipeline.md](9_grasp_pipeline.md) · [8_arm3d_simulator.md](8_arm3d_simulator.md) · [6_digital_twin_safety.md](6_digital_twin_safety.md)

---

## 1. 왜 그리퍼를 디테일하게 만들었나 (설계 근거)

### 1.1 핵심 목표 — "시뮬 데이터를 현실에서 그대로 쓴다"

이 프로젝트의 파지 전략은 [9_grasp_pipeline.md](9_grasp_pipeline.md)의 **FK 샘플링 파지 DB**다.
디지털 트윈(arm3d)에서 관절각을 무작위로 샘플링해 `[관절각 → 그리퍼 TCP 포즈 + 접근벡터 + 충돌라벨]`을
10만 세트 기록하고, 이를 역질의해 "물체 위치 + 접근 방향 → 충돌 없는 관절각"을 얻는다.

그런데 이 데이터의 한 행이 보장하는 것은 다음 뿐이다:

- ✅ 그 관절각이 **운동학적으로 도달 가능**하다
- ✅ 그 자세에서 팔이 **바닥/자기 자신과 충돌하지 않는다**

**보장하지 않는 것:** 그 자세에서 그리퍼를 닫았을 때 **물체를 실제로 움켜쥐는가**.
손가락이 물체를 비껴가면(헛잡음) 도달 가능·충돌 없음이어도 파지는 실패한다.
즉 데이터셋만으로는 "접근 자세"일 뿐 "검증된 파지"가 아니다.

> **그래서 그리퍼 개폐를 시뮬에 넣는다.** 손가락이 닫히는 기구를 정확히 모델링하면, 각 후보 자세에서
> **실제 닫힘 동작을 시뮬레이션**해 손가락-물체 접촉을 판정할 수 있다. 이 검증을 통과한 행만 남기면
> 데이터셋이 "검증된 파지 DB"가 되어 **실물 신뢰성**이 올라간다. 이것이 sim-to-real의 핵심 다리다.

### 1.2 왜 "평행집게(prismatic)"를 정확히 모델링해야 했나

초기에는 손가락을 **회전(pivot) 관절**로 가정했으나, 실제 하드웨어는 두 손가락이 서로 마주 본 채
**미끄러지는(병진, prismatic) 평행집게**다. 이 차이는 접촉 판정에 직접 영향을 준다:

- 회전 모델은 손가락 끝이 호(arc)를 그리며 접촉점·접촉각이 물체 크기에 따라 달라진다.
- 병진 모델은 두 접촉면이 **평행하게 마주 보며 좁혀져**, antipodal 접촉(마주 보는 2점)이 기하학적으로
  명확하다. 파지 안정성(force-closure) 판정과도 일치한다.

따라서 그리퍼를 **프리즈매틱 슬라이드**로 정확히 구현하는 것이, 1.1의 접촉 검증을 신뢰성 있게
만드는 전제 조건이었다.

### 1.3 J7과의 연결 — 시뮬 개폐 = 실물 서보 한 채널

실물 그리퍼는 서보 1개(채널 **ch6**, J7)로 개폐한다(열림 ~550µs, 닫힘 ~2500µs).
시뮬의 개폐 파라미터 `t`(0=열림, 1=닫힘)를 이 펄스 폭에 선형 매핑하면, **시뮬에서 검증한 개폐량을
그대로 실물 명령으로** 보낼 수 있다. 시뮬과 실물이 같은 1-DOF 개폐 모델을 공유하는 것이다.

---

## 2. 어떻게 구현했나 (기구 모델)

### 2.1 결합(mate) 타입에 "그리퍼(grip)" 추가

arm3d의 리깅은 **면결합(mate)** 으로 부모-자식 관절을 만든다([8_arm3d_simulator.md](8_arm3d_simulator.md)).
기존 타입은 **회전(rev)** 과 **고정(fix)** 두 가지였고, 여기에 세 번째 타입 **그리퍼(grip)** 를 추가했다.

| 타입 | 운동 | `applyAngles` 적용 |
|---|---|---|
| `rev` | 회전 | `pv.quaternion = axisAngle(axis, angle−90°)` |
| `fix` | 고정(강체) | 변환 없음 |
| **`grip`** | **병진(슬라이드)** | **`pv.position = base + axis · slide`** (mm) |

손가락 부품(`r→f.1`, `r→f`)을 grip 타입으로 결합/전환(`toGrip` 버튼)한다. 두 손가락은 서로 마주 보며
각자의 슬라이드축을 따라 좁혀진다.

### 2.2 슬라이드축은 그리퍼 로컬 프레임 (자세 따라 회전)

슬라이드 방향 `axis`는 **그리퍼 부모 그룹(pg)의 로컬 프레임**에 저장된다. `pv`(슬라이드 피벗 그룹)는
`pg`의 자식이므로, 손목 관절(J6 등)이 회전하면 `pg`가 회전하고 슬라이드축도 함께 회전한다.
→ **팔이 어떤 자세든 손가락은 항상 그리퍼가 향한 방향으로 곧게 개폐**된다.

축 보정 도구(관절 편집의 **축기울기 / 축위치**)와 **슬라이드축 시각화**(파란 z축 triad + 노란 선)로
손가락이 옆(개폐) 방향으로 미끄러지도록 정렬한다.

### 2.3 개폐 보정 — gOpen / gClose

손가락마다 **완전 열림**과 **완전 닫힘**에서의 슬라이드값을 저장한다(`gOpen`, `gClose`).
이후 `setGripper(t)`가 `slide = gOpen + (gClose − gOpen)·t` 로 두 손가락을 동시에 구동한다.
두 손가락이 반대 방향으로 좁혀지도록 각자 자신의 열림/닫힘 값을 따로 캡처한다.

### 2.4 제어 모드 J7 컨트롤

3D 제어(연동) 모드의 관절 슬라이더 아래에 **J7 · 그리퍼** 개폐 슬라이더를 둔다:

- 슬라이더(0% 열림 ↔ 100% 닫힘) → `setGripper(t)`로 3D 손가락 구동
- 연동(sync) ON + 실물 연결 시 → **ch6** 에 `550 + (2500−550)·t` µs 전송
- 개폐 보정이 안 됐으면 경고 카드로 결합 모드 보정을 안내

---

## 3. 안정성 엔지니어링 — 리깅 드리프트 제거

그리퍼를 결합 과정에서 직접 설정하면서, **재리깅(rebuild)이 현재 자세를 기준점에 구워 넣어** 값이
누적 이동하는 버그가 여러 곳에서 드러났다. 공통 원인과 해결은 다음과 같다.

> **공통 원인:** `rebuild()`는 부품을 평면화한 뒤 다시 리깅하면서, 슬라이드 피벗의 기준점(`_base`)을
> **그 순간의 자세** 기준으로 계산한다. 비휴식(슬라이드·회전된) 상태에서 rebuild가 일어나면 기준점이
> 어긋나 드리프트/대각선 슬라이드가 생긴다.
>
> **공통 해결:** **항상 휴식 자세(회전=90°, 그리퍼=슬라이드 0)에서 리깅**한다.

| 증상 | 트리거 | 수정 |
|---|---|---|
| 축기울기/축위치 시 위치·보정값 누적 이동 | 조정 전 비휴식 상태로 rebuild | 조정 전 `_restFlatten()`(전 관절 휴식 + 평면화) |
| 저장 시 손가락 STL이 멀리 밀림 | 저장이 grip 휴식을 90°(=슬라이드 90mm)로 리셋 | 휴식 리셋을 grip=0으로 |
| 저장해도 개폐 보정이 사라짐 | 직렬화에 `gOpen`/`gClose` 누락 | 직렬화에 추가(로드는 `saved.mates` 직접 복원) |
| 결합/제어 진입 시 손가락 튐 | 모드 진입 rebuild가 stale 슬라이드 적용 | 진입 시 grip=0, rev=90으로 리셋 후 rebuild |
| 자세 잡고 개폐 시 대각선 이동 | 포즈 상태에서 rebuild되어 `_base` 어긋남 | 제어 진입도 휴식 자세에서 리깅 |

이 수정들로 **축 보정 → 개폐 저장 → 저장/재로드 → 어떤 자세에서든 개폐**가 일관되게 동작한다.

---

## 4. 다음 단계 — 손가락-물체 접촉 검출 (파지 검증)

그리퍼 개폐가 정확해졌으므로, 1.1의 목표인 **접촉 검증**을 구현한다:

1. 가상 물체(원기둥/구/컵 등, [9_grasp_pipeline.md](9_grasp_pipeline.md)) 옆에서 `setGripper(t)`로 닫는다.
2. 각 손가락 메시 ↔ 물체 표면의 **접촉/관통**을 검출한다.
3. **양쪽에서 ≥2점 접촉(마주 보는 면)** = ✅ 유효 파지. 한쪽만/없음 = ⚠️ 헛잡음, 관통 = ⚠️ 충돌.
4. 이 판정을 파지 데이터셋 각 후보에 적용 → **검증된 파지만 남긴 DB** → 실물 신뢰성 확보.

이후: 놓기(place) 시퀀스 · 그리퍼 실제 폭 제어 · 실물 검증 · SAM 3D Objects 연동.

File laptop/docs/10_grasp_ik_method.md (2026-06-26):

# 데이터 기반 파지 IK — 방법론 도출 과정과 최종 정식화

> **요지:** 정밀 DH가 없는 자작 6축 팔에서, **보정된 디지털 트윈이 자기 자신을 수만 번 관측해 만든 데이터**로
> "물체 위치 + 접근 자세 → 충돌 없는 관절각"을 푼다. 해석적 IK 대신 **순기구학(FK) 샘플링 + 자세 인지 최근접 탐색**을
> 채택하고, 실패 모드를 하나씩 제거하며 비용함수를 진화시켰다. 본 문서는 **그 도출 과정(왜 각 항이 필요했는가)** 과
> **최종 정식화**를 정리한다.

관련: [9_grasp_pipeline.md](9_grasp_pipeline.md)(구현 명세) · [6_digital_twin_safety.md](6_digital_twin_safety.md) · [4_measurement_validation.md](4_measurement_validation.md)

---

## 1. 문제 정의

6-DOF 관절각 $\theta=(\theta_1,\dots,\theta_6)$ 에 대해 그리퍼 **공구중심(TCP)** 의 포즈를 순기구학으로 얻을 수 있다:

$$p(\theta)=M_{\text{part}}(\theta)\,t_{\text{local}},\qquad R(\theta)=R_{\text{part}}(\theta)\,q_{\text{local}}$$

- $M_{\text{part}}(\theta)$ : 그리퍼가 고정된 STL 부품의 월드 변환(트윈 FK)
- $t_{\text{local}}$ : 부품 로컬에서의 TCP 위치(사용자 지정), $q_{\text{local}}$ : 부품 로컬에서의 TCP **프레임 자세**(확정 시 고정)
- 접근축 $a(\theta)=R(\theta)\,\hat z$ (그리퍼가 물체로 향하는 방향, 프레임 z축)

**목표(역문제):** 물체 위치 $p^\*$ 와 원하는 접근 자세 $q^\*$ 가 주어질 때, **충돌 없이** 그 포즈를 만드는 $\theta$ 를 찾는다.
해석적 IK는 정밀 링크 길이·구면손목을 요구하나 본 팔은 둘 다 불확실 → **데이터 기반 역탐색**을 택한다.

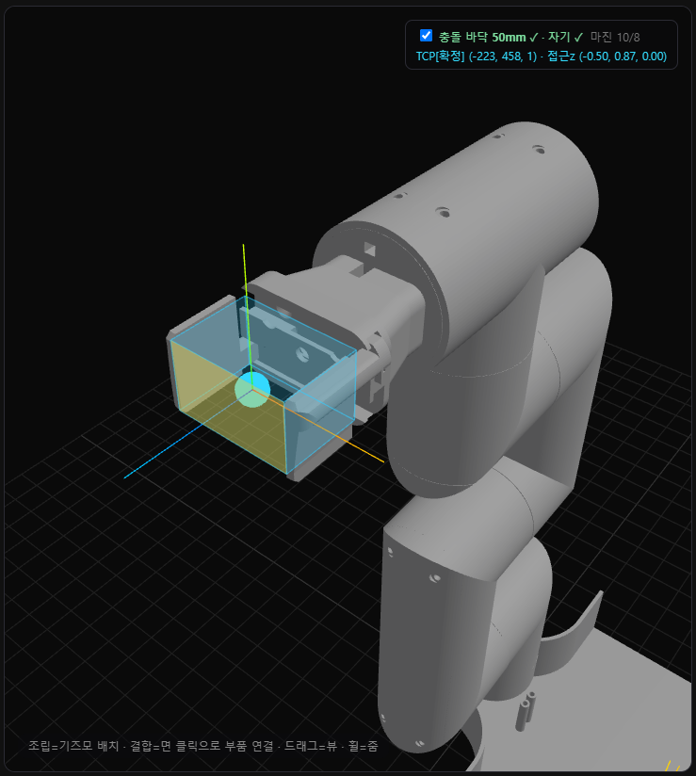
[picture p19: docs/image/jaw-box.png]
그리퍼 TCP·jaw 박스 정의 — 시안 점=TCP, 축 triad(z=접근방향), 노란 박스=jaw 파지 영역. 바닥·자기충돌 마진 표시


---

## 2. 데이터 생성 — FK 샘플링 (관측)

트윈에서 관절을 균일 무작위로 $N$ 회($N{=}10^5$) 쓸어, 각 자세를 관측·기록한다:

$$\mathcal D=\{(\theta^i,\,p^i,\,q^i,\,a^i,\,c^i)\}_{i=1}^{N},\qquad
c^i=\big[\,\text{floor}(\theta^i)<0\ \lor\ \text{self}(\theta^i)<0\,\big]$$

$c^i$ 는 디지털 트윈의 **정확한 기하 충돌검사**(`_collideOnce`, 바닥·자기충돌) 라벨. 충돌 없는 집합 $\mathcal D_{\text{free}}=\{i:c^i=0\}$.
이는 사람이 라벨하지 않은 **자가생성(self-supervised)** 데이터이며, sim-real 마진(바닥 30 mm)으로 "시뮬 안전 ⇒ 실물 안전"이 보증된다.

> **핵심:** $q^i$ 는 단순 접근벡터가 아니라 **그리퍼 프레임 전체 쿼터니언**이다(§3에서 그 필요성이 드러난다).

---

## 3. 비용함수의 진화 — 실패 모드를 제거한 과정 ★

본 연구의 방법론적 기여는 **하나의 비용함수를 단번에 설계한 것이 아니라, 시뮬에서 드러난 실패를 관측하며 항을 더해 간 것**이다.

### v1. 위치 최근접 (position-only)
$$\theta^\*=\theta^{\arg\min_{i\in\mathcal D_{\text{free}}}\ \lVert p^i-p^\*\rVert}$$
**실패:** TCP가 물체에 닿기만 하면 그리퍼 방향이 임의 → "물체 주변으로 가기만 하고 잡는 자세가 아님". 방향 제약 필요.

### v2. 위치 + 접근축 (approach-axis)
접근축 $a^\*=R(q^\*)\hat z$ 와의 정렬을 콘($35^\circ$)으로 필터:
$$\min_{i}\ \lVert p^i-p^\*\rVert + w\,\angle(a^i,a^\*)\quad\text{s.t.}\ \ a^i\!\cdot a^\* > \cos 35^\circ$$
**실패:** 접근축은 맞아도 **축 둘레 회전(roll)이 자유** → 손목이 접힌 기괴한 자세(예 $J_4{=}149^\circ,J_5{=}155^\circ$)도 통과. **자세 전체** 제약 필요 → 데이터에 $q^i$ 기록(재스윕).

### v3. 위치 + 전체 자세 (full 6-DOF)
측지 각거리 $d_q(q_1,q_2)=2\arccos|q_1\!\cdot q_2|$ 로 자세 전체를 매칭:
$$\theta^\*=\theta^{\arg\min_{i}\big[\lVert p^i-p^\*\rVert + w\,d_q(q^i,q^\*)\big]},\qquad \text{s.t.}\ d_q(q^i,q^\*)<\tau\ (\tau{=}45^\circ)$$
**효과:** roll까지 맞춰 **의도한 깔끔한 파지 자세**. **실패(잔존):** 목표 자세 $q^\*$ 를 **고정 프리셋 공식**으로 주니(예 "수평=베이스쪽 수평"), 물체 위치에 따라 **실제 도달 가능한 방향과 어긋남** → 근처에 후보가 많아도 "도달 불가"(실측: 같은 위치에 수평 후보 143개가 있는데 IK는 299 mm 미스).

### v4. 데이터 기반 자세 스냅 (reachability-aware) — 최종
프리셋 공식을 버리고, **그 위치에서 실제 도달 가능한 자세를 데이터에서 가져온다.** 접근 종류 $c\in\{\text{수직},\text{수평}\}$ 에 대해
$$q^\*(c,p^\*)=q^{\arg\min_{i\in\mathcal D_{\text{free}},\,\text{class}(a^i)=c}\ \lVert p^i-p^\*\rVert},\qquad
\text{class}(a)=\begin{cases}\text{수직}& a_y<-0.6\\[2pt]\text{수평}& |a_y|<0.4\end{cases}$$
이렇게 얻은 $q^\*$ 로 v3 을 풀면 **항상 도달 가능한 자세**가 나온다(그 위치에 종류 $c$ 후보가 없으면 명시적으로 "불가" 보고 — §5의 capability 와 일관).

> **교훈:** "원하는 자세를 공식으로 지정"하는 것보다 **"가능한 자세를 데이터에서 찾아 제시"** 하는 편이, 위치 의존적 도달성을 자연히 존중한다.

---

## 4. 경로 정식화 — 충돌 없는 전환 (P4)

IK 가 주는 것은 *목표 자세*일 뿐, 거기까지의 **이동 경로**는 별도다. 직선 보간 $\ell(\theta_a,\theta_b,t)=(1-t)\theta_a+t\theta_b$ 가
중간에서 바닥을 뚫을 수 있다(수직↔수평 전환). 경로 안전성:

$$\text{clear}(\theta_a,\theta_b)=\bigwedge_{t\in\{1/m,\dots,1\}}\neg\,\text{collide}\big(\ell(\theta_a,\theta_b,t)\big)\quad(\sim3^\circ\ \text{간격})$$

경로 계획 $\Pi(\theta_{\text{from}},\theta_{\text{to}})$:
$$\Pi=\begin{cases}[\theta_{\text{to}}] & \text{clear}(\theta_{\text{from}},\theta_{\text{to}})\\[2pt]
[w,\theta_{\text{to}}] & \exists\,w\in\mathcal W:\ \text{clear}(\theta_{\text{from}},w)\land\text{clear}(w,\theta_{\text{to}})\\[2pt]
\varnothing & \text{(안전 경로 없음 → 보고)}\end{cases}$$

경유점 후보 $\mathcal W=\{\,\text{업라이트}(90^\circ{\times}6),\ \text{어깨·팔꿈치 들기}\,\}$ — 바닥 여유가 큰 자세. 큐를 순차 추종.
**위치(L2 ladder):** 이는 학습이 아닌 **휴리스틱 + 정확 충돌검사**다. "데이터 기반 최적 경로"는 비용기반 탐색(RRT\*) 또는 **RL 모션 정책**(L2)으로의 확장 대상이다(§7).

---

## 5. 방향 조건부 도달영역 (capability map)

같은 위치라도 수직/수평 가능 여부가 다르다. 작업공간을 복셀 $v$ 로 나눠
$$\text{feasible}(v,c)=\big|\{\,i\in\mathcal D_{\text{free}}:\ \text{vox}(p^i)=v,\ \text{class}(a^i)=c\,\}\big|\ge k$$
로 정의(런타임 조회는 가장자리 양자화를 피해 **반경 스캔**). 이는 **AI 접근전략 결정의 근거이자 타당성 검증층**이다:
AI가 접근 종류를 제안 → capability 가 그 위치에서 가능한지 검증 → 6-DOF IK 가 자세 해석 → P4 가 경로.

---

## 6. 실측 결과

| 항목 | 값 (디지털 트윈, $N{=}10^5$) |
|---|---|
| 충돌 없는 자세 비율 | 91.5% (충돌 8.5%) |
| 작업공간 | 반구형 X[−415,376] Y[13,527] Z[−408,407] mm |
| 위치 최근접 잔차(밀도) | 중앙 **5.7 mm** |
| **6-DOF IK 잔차**(자세 $45^\circ$ 이내) | 위치 중앙 **11 mm**·90p 21 mm·후보없음 0 |
| 〃 ($30^\circ$ / $20^\circ$ 이내) | 14 mm / 20 mm |
| capability(복셀 35 mm) | 수직만 475 · 수평만 1506 · 둘다 1678 |

→ **방향(roll)까지 제약해도 위치 잔차 ~11 mm**(sim-real 마진 30 mm 안) = 깔끔한 파지 자세를 정밀하게 해석. 접근 종류별 도달영역이 정량적으로 분리됨(수평만 영역이 큼 = 측면 접근 가용지가 넓음).

---

## 7. 학술적 위치 / 한계 / 향후

- **자가생성 데이터 기반 역기구학:** 정밀 모델 없이, 보정된 트윈의 자기관측으로 IK·도달성·파지 자세를 푼다. C-space 충돌예측층과 동일 철학(저비용 웹캠+STL 트윈).
- **방법론 도출의 정직성:** 비용함수는 **실패 모드(임의 자세 → roll 접힘 → 도달성 무시)를 관측하며 항을 더해** 최종형(데이터 스냅)에 이르렀다 — 일종의 **절제 실험(ablation) 서사**.
- **데이터 기반의 경계:** *잡는 자세*는 데이터 기반(관측 조회)이나, *움직이는 경로*는 아직 휴리스틱이다. 진정한 "데이터 기반 최적 경로"는
  ① 같은 충돌 데이터 위 **비용기반 탐색(RRT\*/A\*)**, ② 보정 트윈에서의 **RL 모션 정책(L2)** 으로의 확장으로 달성된다. 트윈은 그 전제조건을 이미 충족한다.
- **향후:** 파지 시퀀스(프리그래스프→접근→닫기→들기) 완성 → 비용 최적화 → RL → AI 서버 자연어 파이프라인에 capability·IK·경로 연결.

> 수치·정식화는 2026-06-19 실측 기준. 조립·보정·TCP 변경 시 재스윕으로 갱신.

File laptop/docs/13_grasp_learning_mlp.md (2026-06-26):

# 파지 학습 MLP — 무엇을 참고했고, 무엇을 얻기 위해 쓰는가

> **요지:** 디지털 트윈이 **가상 jaw로 자동 라벨링한 파지 데이터**(`grasp_learn.csv`)로, 작은 신경망
> (scikit-learn MLP)을 학습해 **"물체(위치·형상·크기) + 접근(수직/수평) → 잡을 수 있나"** 를 즉시
> 판정하고, **수직 vs 수평 접근을 스스로 선택**하게 만든다. C-space 충돌예측 신경망과 **같은 레시피**를
> 파지에 적용한 것이다. 구현: [`calibration/grasp_learn.py`](../calibration/grasp_learn.py).

관련: [12_grasp_orientation_learning.md](12_grasp_orientation_learning.md) · [6_digital_twin_safety.md](6_digital_twin_safety.md) · [11_gripper_design.md](11_gripper_design.md)

---

## 1. 무엇을 참고했나 (토대)

| 토대 | 내용 | 본 프로젝트에서의 역할 |
|---|---|---|
| **자체 선행연구 — C-space 충돌예측** ([6_digital_twin_safety.md](6_digital_twin_safety.md), `cspace_learn.py`) | 시뮬이 스스로 만든 충돌지도로 MLP가 "관절각 → 안전/위험"을 학습(정확도 98.9%) | **동일 레시피를 파지에 그대로 적용.** 라벨러만 충돌검출 → **가상 jaw 파지검출**로 교체 |
| **FK 샘플링 파지 DB** ([9_grasp_pipeline.md](9_grasp_pipeline.md)) | 해석적 IK 대신 디지털 트윈으로 관절각↔TCP 포즈를 샘플링한 데이터베이스 | 학습 데이터의 **도달 가능 자세 후보** 공급원 |
| **가상 jaw 파지 모델** ([11_gripper_design.md](11_gripper_design.md), §본 문서 3) | 그리퍼 손가락 사이의 파지 영역을 TCP 기준 박스로 모델링 → 끝으로 잡아도 유효, 깊을수록 안전 | 데이터의 **성공/실패 자동 라벨러** (사람 개입 없음) |
| **scikit-learn** (`MLPClassifier`, `MLPRegressor`, `StandardScaler`) | 다층 퍼셉트론·표준화 등 표준 ML 도구 | 모델 구현 라이브러리 |
| **다층 퍼셉트론(MLP) · 오차역전파 · 지도학습** | 입력→은닉층→출력, forward/backprop/경사하강으로 가중치 최적화 | 모델의 학습 원리 |
| **평행집게 antipodal 파지** 개념 | 두 손가락이 물체를 양쪽에서 감싸야 안정 파지 | 라벨 기준(파지 유효성)의 물리적 근거 |

> 핵심 사상은 **"의미는 위로, 결정적·실시간은 아래로"**([architecture](../../docs/1_architecture.md))의 연장 —
> 무거운 검색·시뮬을 **오프라인 학습**으로 압축해, 런타임엔 µs급으로 질의한다.

---

## 2. 입력 데이터 — `grasp_learn.csv`

디지털 트윈(arm3d, 4페이지 "파지 학습 데이터 생성")이 **물체를 워크스페이스 곳곳·바닥에 놓고**, 각 물체마다
**수직·수평 접근을 둘 다 시도**해 가상 jaw로 자동 라벨링한다(물체당 2행).

| 열 | 의미 | 용도 |
|----|---|---|
| `obj_x,obj_y,obj_z` | 물체 중심 3D 위치(mm, 바닥에 놓임: y=바닥+H/2) | **입력 특징** |
| `type, R, H` | 형상(0=원기둥…)·반경·높이 | **입력 특징** |
| `approach` | 0=수직(top-down)·1=수평(side) | **입력 특징** |
| `success` | jaw 안에 잡히면 1, 아니면 0 | **분류 정답(y)** |
| `perp` | 닫힘축 중심오차(정렬) | 품질 진단 |
| `secure` | 베이스로부터 깊이(0=깊음·안전 … 클수록 끝·얕음) | 파지 **안전도**(향후 학습 대상) |
| `J1…J6` | 그 파지의 관절각(성공 시) | **회귀 정답** |

**자동 라벨 규칙(가상 jaw):** 물체 중심을 TCP/jaw 로컬로 변환해 ① 벌림 W 안에 들어오고(2R≤W) ②
닫힘축 중심에 있고 ③ jaw 깊이·높이 안이면 = **파지 성공**. 그리퍼 손끝 면까지 닿으면 최소 파지로 인정,
TCP(베이스)에 가까울수록 `secure`(안전)가 좋다. → [11_gripper_design.md](11_gripper_design.md).

---

## 3. 모델 구조와 전처리

```
입력 X = [obj_x, obj_y, obj_z, type, R, H, approach]   (7차원)
        │  StandardScaler (평균0·분산1 정규화)
        ▼
   [MLP 은닉층 64 → 64, ReLU]
        ▼
 분류기 출력: P(파지 가능)        회귀기 출력: J1…J6 (성공 샘플만)
```

- **정규화(StandardScaler):** 위치(±400)·반경(5~35)처럼 스케일이 다른 특징을 같은 크기로 맞춰, 큰 값이
  학습을 지배하지 않게 한다.
- **train/test 분리:** 80% 학습 / 20% 평가(`stratify`로 성공·실패 비율 유지) → **외운 게 아니라 일반화**했는지 측정.

---

## 4. 학습 방법 (MLP가 배우는 원리)

데이터 한 묶음마다 다음을 수백 번(`max_iter`) 반복한다.

1. **순전파(forward):** 입력 × 가중치 + 편향 → ReLU(비선형) → 예측 확률
2. **손실(loss):** 예측 vs 정답의 오차(분류=cross-entropy, 회귀=MSE)
3. **역전파(backprop):** 오차를 줄이려면 각 가중치를 **어느 방향**으로 바꿀지 미분으로 계산
4. **경사하강(gradient descent):** 그 방향으로 가중치를 조금씩 갱신

반복하면 가중치가 "이런 위치·형상·접근이면 잡힌다/아니다"의 패턴을 담는다. 비선형(ReLU) 은닉층이
있어 **단순 직선 경계로 못 나누는 복잡한 파지가능 영역**(고리·바닥제약 등)도 근사할 수 있다.

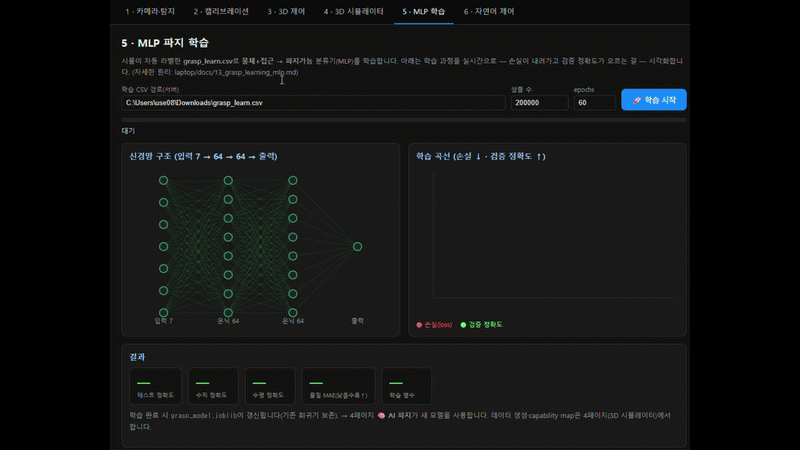
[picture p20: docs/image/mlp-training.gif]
5페이지 MLP 학습 콘솔 — epoch마다 손실·검증 정확도가 갱신되는 학습 과정


> 🎬 데모 영상: [MLP 파지 학습](https://drive.google.com/file/d/1riFp9NCgwCPHXfsDhdb2TVaCAP688P8R/view?usp=sharing)

---

## 5. 얻는 결과값 (출력)과 성능

| 모델 | 입력 → 출력 | 성능(166k행·반경≤30 기준) |
|---|---|---|
| **분류기** | 물체+접근 → **파지 가능?**(확률) | 테스트 정확도 **92.7%** (수직 92.3·수평 93.2) |
| **접근 선택** | 물체 → `P(수직)` vs `P(수평)` 비교 → **수직/수평 결정** | 결정적 물체 정확도 **86.8%** |
| **회귀기** | 물체 → **관절각 J1…J6**(초기 자세) | MAE **31.6°**(다봉성 — 런타임 IK/검색 보정 전제) |

- **분류기**가 핵심 산출물 — C-space 안전지도의 **파지 버전(capability map)**.
- **접근 선택**은 분류기를 수직·수평 두 번 질의해 argmax → "AI가 형상·위치로 접근 방식을 판단".
- 산출 파일: `calibration/grasp_model.joblib`(분류기·회귀기·스케일러), `docs/image/grasp-learned.png`(수직·수평 맵),
  `grasp-learned-3d.png`(3D 파지가능 영역).

실행:
```bash
python calibration/grasp_learn.py <grasp_learn.csv>   # 학습+평가+그림+모델저장 일괄
```

---

## 6. 무엇을 위해 쓰는가 (용도)

**런타임 자동 파지의 "판단·제안층"** 이다(= 파지용 AI 검증층):

```
비전(3D 좌표 + 형상 R·H·type)
   → 분류기로 수직·수평 파지가능 즉시 판정 → 더 높은 접근 선택
   → 회귀기로 초기 관절각 제안 → IK/검색으로 정밀 보정 → 실행(J1~J6 + 그리퍼)
```

수천 자세를 매번 검색하지 않고 **µs급 추론으로 "잡을 수 있나 + 어떻게"** 를 답한다. AI 서버가 명령을
내릴 때, 노트북이 이 모델로 **실물 실행 전에 파지 타당성을 검증**한다.

---

## 7. 한계와 다음

- **회귀 다봉성:** 한 물체에 여러 파지가 있어 관절각 직접 예측은 평균이 됨(MAE 31°) → 런타임 검색/IK로 보정.
- **`secure`(안전도) 학습 미적용:** 현재는 가능/불가만 학습. 깊이(안전)까지 회귀·랭킹으로 학습하면 "더
  안전한 파지" 선택 가능.
- **능동학습 미적용:** 모델이 애매한(P≈0.5 경계) 물체를 골라 시뮬로 재라벨·재학습하면 경계 정확도↑
  (C-space 능동학습과 동일).
- **데이터 충실도:** 가상 jaw·바닥 기준이 실제 그리퍼와 정확히 맞아야 함(시각 조절·저장으로 보정).
- **다음 단계:** 런타임 'AI 파지 제안'(Django 엔드포인트로 모델 서빙) → 능동학습 → 실물 검증.

---

## 8. 손목(J6) roll 최적화 — 문헌 근거

6-DOF 파지 자세는 **접근축(approach) + 그 축 둘레의 roll 각도**로 정해지며, 이 **roll(우리 팔의 J6/손목)**
을 명시적으로 샘플·최적화하는 것이 6-DOF 파지 생성 연구의 공통 원리다([R1]~[R4]).

- **Approach-based 샘플링([R2]):** 표면 법선에 그리퍼를 정렬(접근 콘 반각 이내) + 접근각·**roll 각도**를 샘플.
- **Antipodal 샘플링([R2][R3]):** 표면 접촉점 쌍을 잡고 그 축 둘레 **roll 회전**을 샘플 → force-closure로 평가.

**본 프로젝트 적용:** FK-샘플링 DB는 J6가 균일 랜덤이라 밀도가 낮으면 잘 정렬된 roll을 못 찾는다. 그래서
런타임 'AI 파지'에서 DB 최적 자세를 찾은 뒤, **손목(J4·J5·J6)을 국소 hill-climb으로 미세조정해 jaw
정렬(닫힘축 중심오차)을 최소화**한다(`_refineWrist`, 충돌 시 원본 복귀). 근본 개선은 **더 조밀한 DB** 또는
**객체 중심 antipodal+roll 생성**([R2][R3])이다.

---

## 9. 참고문헌

**6-DOF 파지 자세 생성 · roll/접근 샘플링**
- [R1] A. Mousavian, C. Eppner, D. Fox. *6-DOF GraspNet: Variational Grasp Generation for Object Manipulation.* ICCV 2019. <https://openaccess.thecvf.com/content_ICCV_2019/papers/Mousavian_6-DOF_GraspNet_Variational_Grasp_Generation_for_Object_Manipulation_ICCV_2019_paper.pdf>
  — 파지 자세를 변분 생성. 접근+roll 6-DOF 표현의 대표 연구.
- [R2] J. Huber et al. *Speeding up 6-DoF Grasp Sampling with Quality-Diversity.* arXiv:2403.06173, 2024. <https://arxiv.org/pdf/2403.06173>
  — **approach-based/antipodal 샘플링의 파라미터(접근각·콘 회전·roll 각도)** 를 명시. 본 프로젝트의 roll(J6) 최적화 근거.
- [R3] *QuickGrasp: Lightweight Antipodal Grasp Planning with Point Clouds.* arXiv:2504.19716, 2025. <https://arxiv.org/html/2504.19716v1>
  — 점군에서 antipodal 파지 계획(경량). 접촉점+roll 샘플링·force-closure.
- [R4] *GraNet: A Multi-Level Graph Network for 6-DoF Grasp Pose Generation in Cluttered Scenes.* arXiv:2312.03345, 2023. <https://arxiv.org/pdf/2312.03345>
  — 군집 장면 6-DOF 파지 생성(그래프 신경망).

**학습 도구 · 방법론**
- [R5] F. Pedregosa et al. *Scikit-learn: Machine Learning in Python.* JMLR 12, 2011. <https://jmlr.org/papers/v12/pedregosa11a.html>
  — 본 프로젝트의 `MLPClassifier`/`MLPRegressor`/`StandardScaler` 구현 라이브러리.
- [R6] 자체 선행연구 — **디지털 트윈 안전 + C-space 충돌예측**. → [6_digital_twin_safety.md](6_digital_twin_safety.md).
  — 시뮬 자가라벨 → MLP 학습 → 능동학습의 동일 레시피(파지에 그대로 적용).

> 개념 토대: **antipodal 파지·force closure**(평행집게 안정 파지 기준), **다층 퍼셉트론·오차역전파**(지도학습).

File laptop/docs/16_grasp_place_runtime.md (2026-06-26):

# 16. 파지·놓기 실행 런타임 (Grasp & Place Runtime)

> 📂 [루트](../../README.md) → [laptop](../README.md) → [laptop/docs](README.md) → **16 (실행 런타임)**

> **이 문서의 역할.** [13_grasp_learning_mlp.md](13_grasp_learning_mlp.md)가 "어디를·어떤 접근으로 잡을지"를 **결정(학습)**하는 부분이라면,
> 이 문서는 결정된 파지를 **실제로 집고 → 들고 → 옮기고 → 놓는** 실행 파이프라인을 명세한다.
> 시뮬레이터([8_arm3d_simulator.md](8_arm3d_simulator.md)) 4페이지의 「가상 물체」 카드에서 동작하며, 실물 연동/AI 서버 연동(다음 단계)의 기준 시퀀스가 된다.

---

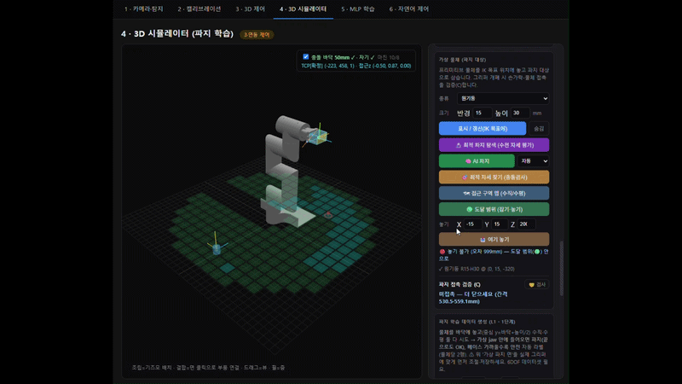
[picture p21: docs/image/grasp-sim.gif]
파지 학습 결과로 동작하는 4페이지 3D 시뮬레이터 — 가상 물체 표시 → AI 파지(수직/수평·품질) → 잡기·들기·놓기


> 🎬 데모 영상: [잡기·놓기 ①](https://drive.google.com/file/d/1SrEo43e4rWohGsKSrXign7xtEpKEwyvU/view?usp=sharing) · [②](https://drive.google.com/file/d/1nPFacq3uxQnlIRRXGvIO_LedIHU8A4sO/view?usp=sharing) · [③](https://drive.google.com/file/d/1vkNTbvnbb-N0b4rIz5xn-92pryiSB7c0/view?usp=sharing)

## 0. 한눈에 — 전체 흐름

```
[물체 표시] ──▶ 🧠 AI 파지 ────────────────────────────────┐
                 │ MLP: 수직/수평 + 품질 판정                 │
                 │ _searchObjGrasp: jaw 도달 자세 검색         │
                 │ _refineWrist: 손목(J4~J6) roll 미세조정      │
                 ▼                                            │
        executeGraspTwoStage  ── 이상자세 정렬(가능한 만큼)    │
                 │  ① standoff(접근축 −80mm, 그리퍼 열림)       │ 실패/막힘
                 │  ② 직선 접근 → 닫기 → 물체 부착(_attachObj)   │   ▼
                 │  ③ 들기(+100mm)                             │ _directGrasp(폴백)
                 ▼                                            │ 이동+닫기+부착+들기
        [_held = 물체 부착됨] ◀───────────────────────────────┘
                 │
                 ▼  📥 여기 놓기
        executePlace  ── 자이로 수평 레벨링(접근 수평 시)
                 │  ① 들어올림  ② 운반(목표 위, 바닥 회피)
                 │  ③ 하강 → 열기 → 분리(_detachObj)
                 │  ④ 후퇴
                 ▼
              [놓기 완료]
```

핵심 상태값:
| 변수 | 의미 |
|---|---|
| `vObj` | 가상 물체(THREE.Mesh, 프리미티브 sph/cyl/box) |
| `_held` | 잡고 있는 물체. `{localPos}` = 부착 시점 TCP-로컬 오프셋. null=빈손 |
| `graspSeq` | 실행 중 시퀀스 `{steps:[{joints,grip,label}], i}` |
| `gjaw` | 가상 jaw(노란 면) 박스. TCP 기준 파지 판정의 기준틀 |

---

## 1. 저수준 빌딩블록

### 1-1. 연속 자세 IK — `_ikToPose(j0, tPos, tQuat, iters, ow)`
주어진 시작 관절 `j0`에서 **목표 TCP 위치 `tPos` + 자세 `tQuat`**로 수렴시키는 국소(hill-climb) IK.

```
비용 _poseErr = |위치오차(mm)|  +  자세오차(도) × ow
```
- 6개 관절을 ±step(12°→0.4°)으로 좌표하강, 개선 없으면 step 절반.
- 반환: `{j(관절), err(비용), posErr(mm), angErr(자세 잔차°)}`.
- **`ow`(orientation weight, 기본 1.5)가 핵심 손잡이.** 클수록 위치보다 자세 정렬을 우선 → 같은 위치를 맞추되 **손목(특히 J6)을 더 돌려** 노란 면을 원하는 방향으로 유지한다. → 놓기 자이로(§4)에서 `ow=4` 사용.

연속(continuous) IK인 이유: standoff→접근→들기처럼 **이전 자세에서 조금씩만 움직이는** 경로를 만들기 위해. 매번 전역 검색하면 자세가 튄다.

### 1-2. 보조
| 함수 | 역할 |
|---|---|
| `_tcpOfJoints(j)` | 관절 `j`의 TCP 포즈 `{pos,q}` 계산 후 **자세 원복**(부작용 없음) |
| `_tcpPose()` | 현재 적용된 관절의 TCP 포즈 `{ok,pos,quat,approach,part}` |
| `pathClear(jA,jB)` | 두 자세 사이 직선 보간 경로가 충돌 없는지 |
| `seqNext()/seqStepDone(st)` | 시퀀스 한 스텝 실행. `grip:'close'`→`setGripper(1)`+`_attachObj()`, `grip:'open'`→`setGripper(0)`+`_detachObj()` |

상수: `GRASP_STANDOFF=80mm`(프리그래스프 후퇴), `GRASP_LIFT=100mm`(들기 높이).

---

## 2. 두 단계 집기 — `executeGraspTwoStage(Gj, label, approach, O)`

> 입력: `Gj`(파지 후보 관절), `approach`('vert'|'horz'), `O`(물체 중심 월드).
> 한 번에 물체로 돌진하지 않고 **standoff에서 정렬 → 직선으로 접근**한다(노란 면 꺾임·측면 충돌 방지).

1. **이상 자세 정렬(가능한 만큼).** 후보 `Gj`의 TCP 자세를 그대로 쓰지 않고 *이상적 방향*으로 재정렬을 시도:
   - 수직: 접근축 z=`(0,−1,0)`(정아래), 노란 면 수평.
   - 수평: 접근축 z=수평으로 **물체 중심을 향함**, 손가락축 y=수직.
   - 이상 자세 `qi`로 "물체가 jaw 중심(`gjaw.cx,cy,cz`)에 오는" TCP를 `_ikToPose`로 풂.
   - `posErr<25mm`면 채택, 남은 자세 잔차 `angErr`를 **기울기(tilt)**로 보고. → 구조적으로 완전한 수직/수평이 안 되는 위치에서도 "**할 수 있는 만큼**" 정렬하고 한계를 숫자로 드러냄.
2. **standoff.** 실제 도달한 접근축 A를 따라 `−80mm` 뒤 지점으로 `_ikToPose` → 프리그래스프 자세(그리퍼 열림).
3. **경로 검사.** `pathClear(pre, G)`로 직선 접근이 충돌 없는지. 막히면 → `_directGrasp(원본 G)` 폴백.
4. **시퀀스 생성:**
   - ① 프리그래스프(정렬) — `grip:'open'`, 라벨에 기울기° 표기(>15°면 "팔 구조 한계").
   - ② 직선 접근·파지 — `grip:'close'` → 부착.
   - ③ 들기(+100mm).

### 폴백 — `_directGrasp(Gj, label)`
두 단계가 불가(standoff 못 풂/경로 막힘)할 때: 후보 G로 **직접 이동 + 닫기 + 부착**, 도달되면 들기까지. (초기 버전은 닫기/부착을 빠뜨려 "잡았는데 안 들림" 버그가 있었음 → §6 참조.)

---

## 3. 충돌 인식 — 손가락은 허용, 몸체는 금지

파지 자세가 **그리퍼 몸체(손가락 제외)나 팔이 물체를 파고들면** 무효다. 물체를 손가락 사이가 아니라 손등/링크로 "밀고" 있는 가짜 파지를 거른다.

| 함수 | 방식 | 용도 |
|---|---|---|
| `_gripperHitsObject(invObj,type,R,H)` | grip 체인 중 **손가락 제외** 메시 정점을 물체 SDF로 검사, 3mm↑ 침투=충돌 | 정밀(관절 적용) |
| `_bodyHitsObject(pos,quat,...)` | TCP 프레임에 사전계산한 몸체 점군 — 관절 적용 없이 빠름 | 대량 라벨링/검색 |
| `_evalGraspFull(j,...)` | jaw 품질 + 몸체 충돌, `cost += 충돌?500` | 최적 자세 탐색 |

> SDF(`_objSDF`): sph=구, cyl/cup=원기둥(측면 부호거리), box=상자. 물체-로컬(중심 원점, 축=Y) 기준.

---

## 4. 놓기 — `executePlace()` (J6 자이로 수평 유지)

> 든 물체(`_held`)를 `(plX, plY, plZ)`에 안전하게 내려놓는다. **공중 좌표·바닥 쓸기·물체 기울어짐**을 모두 방지.

1. **놓을 높이.** `plY` 비면 `floorY + H/2`(바닥에 안착).
2. **🔑 자이로 레벨링.** 현재 든 자세의 접근축 z가 수평에 가까우면(`|z.y|<0.7`) **손가락축 y를 수직(up)으로 재정렬**한 자세 `q`를 만든다 → 노란 면이 꺾이지 않고 수평 유지. (수직 파지는 이미 똑바라 생략.)
3. **`ow=4`로 IK.** 들어올림→운반→하강 세 구간 모두 자세 가중치를 높여 `_ikToPose(..., 90, OW)` → **J6가 충분히 회전**해 운반 내내 jaw 수평을 유지. (이전엔 위치만 맞추느라 J6를 덜 돌려 물체가 기울었음.)
4. **운반 높이** `transY = max(현재y, 목표y) + 90mm` → 가는 길에 바닥/물체를 쓸지 않음.
5. **물체 추적 오프셋** `offW = _held.localPos ⟲ q`. `tcpFor(물체중심)=물체중심−offW` 로 물체가 목표에 오도록 TCP 목표를 역산.
6. **시퀀스:** ① 들어올림 ② 운반(목표 위) ③ 하강+`grip:'open'`(분리) ④ 후퇴. 도달오차 40mm↑면 "도달 불가 — 접근맵 가능구역으로" 거부.

### 부착/추적 — `_attachObj / _updateHeld / _detachObj`
- `_attachObj()`: 닫는 순간 물체의 TCP-로컬 오프셋을 `_held.localPos`로 고정(강체 부착).
- `_updateHeld(t)`: 매 프레임 물체를 TCP에 붙여 따라가게 하고, **IK 목표(ikX/Y/Z)도 든 물체로 갱신** → "물체 옮겼는데 놓기 좌표가 안 따라옴" 해결.
- `_detachObj()`: 열기 시 분리.

---

## 5. 운영 도구 (가상 물체 카드 버튼)

| 버튼 | 함수 | 동작 |
|---|---|---|
| 🧠 AI 파지 | `aiGrasp` | MLP가 수직/수평+품질 판정 → 접근 선택(자동/강제) → `_searchObjGrasp`로 자세 검색 → `_refineWrist` → 두 단계 집기. **주 진입점.** |
| 🎯 최적 자세 찾기 | `optimizeGraspForObject` | 물체 고정, 근처 DB 자세를 **전수 평가**(jaw 쏙+충돌없음+깊이) → 최적 1개 → 손목 정밀화 → 실행. MLP 없이 그 위치 한계 확인용. |
| 🗺 접근맵 | `approachMap` | 이 물체 크기로 워크스페이스를 격자 스캔, 각 셀에서 수직/수평 도달 기울기<20°인지 → **파랑(수직)·초록(수평)·청록(둘다)** 구슬. `approach_map.csv` 저장. |
| 📥 여기 놓기 | `executePlace` | §4 |

### 손목 정밀화 — `_refineWrist(j0, ...)`
J4·J5·J6만 ±step으로 hill-climb해 jaw 정렬 cost 최소화(roll 포함). 충돌 시 원본 복귀.
근거: 6-DOF 파지 샘플링의 'roll 각도' 최적화(approach-based/antipodal). DB 밀도 한계를 국소 보정. → [13 §9 참고문헌](13_grasp_learning_mlp.md).

### 접근맵이 드러낸 구조적 한계
접근맵 결과: **도달 가능 영역이 환형(annular)** — 팔에서 적당히 떨어진 링에서는 수직/수평이 되지만, **베이스 바로 앞(근접부)은 수직 파지 사각지대**. 이는 MLP의 한계가 아니라 **6-DOF 팔의 기구학적 구조 한계**다(짧은 링크로 베이스 근처에서 손목을 정아래로 못 세움). 실전 배치 시 물체를 이 가능 구역 안에 두는 것이 전제.

---
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

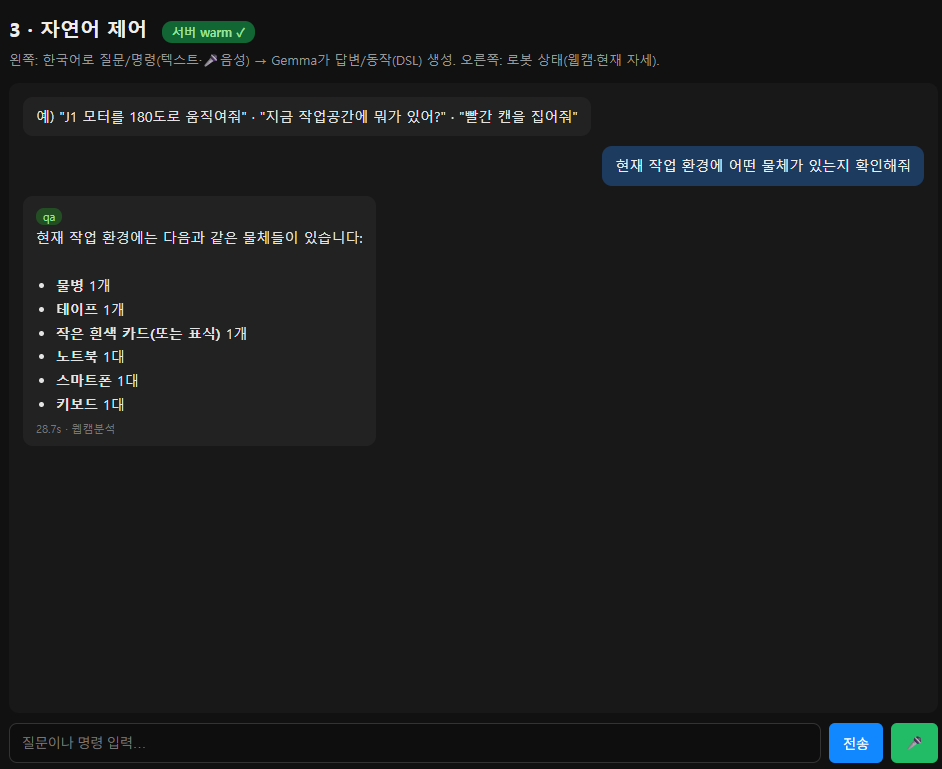
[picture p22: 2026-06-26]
docs/image/vlm-chat.png

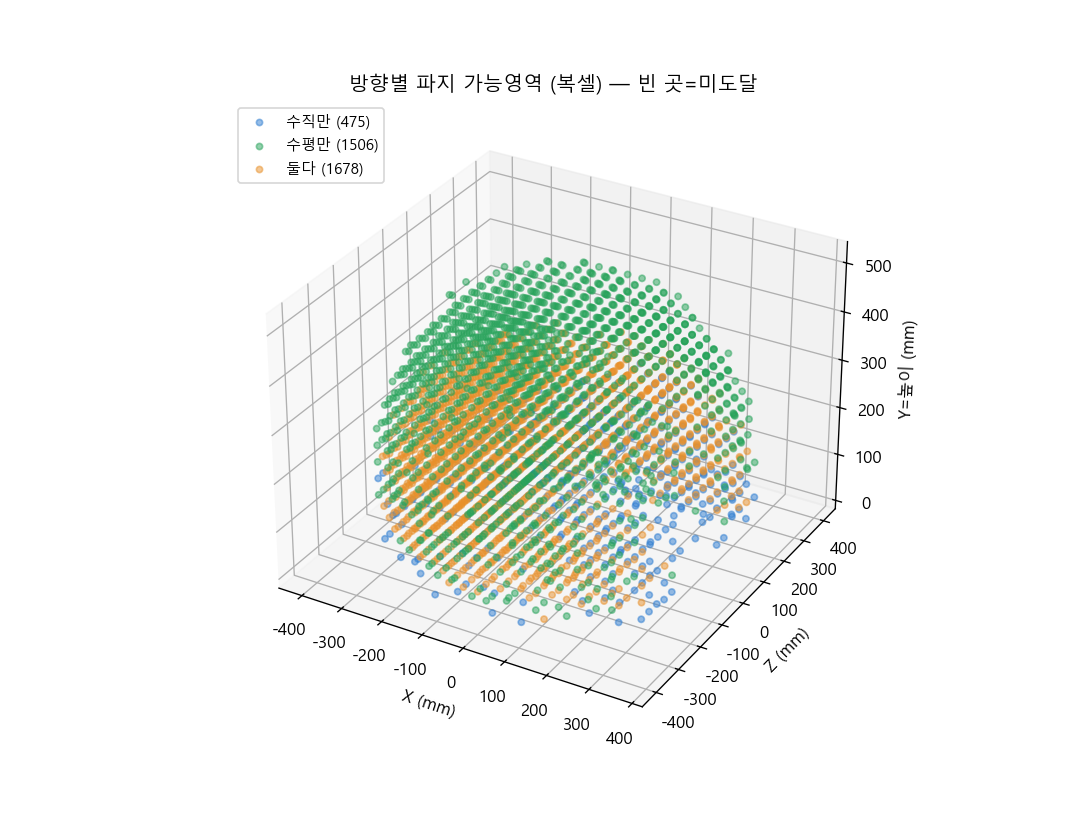
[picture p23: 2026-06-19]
docs/image/grasp-capability3d.png

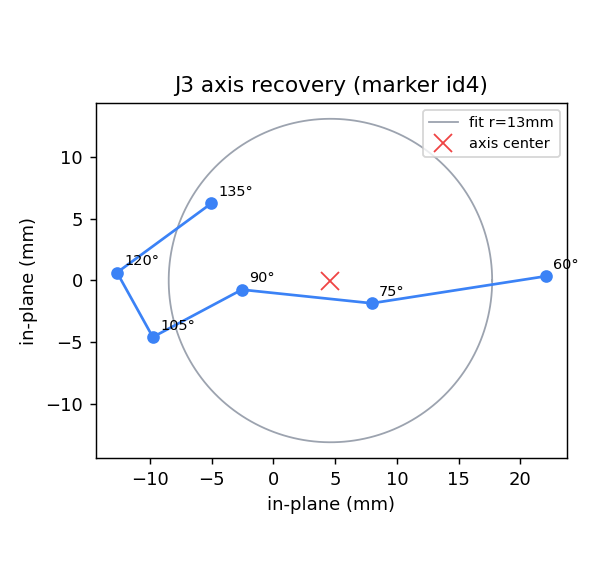
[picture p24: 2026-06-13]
docs/image/val-axis-j3.png

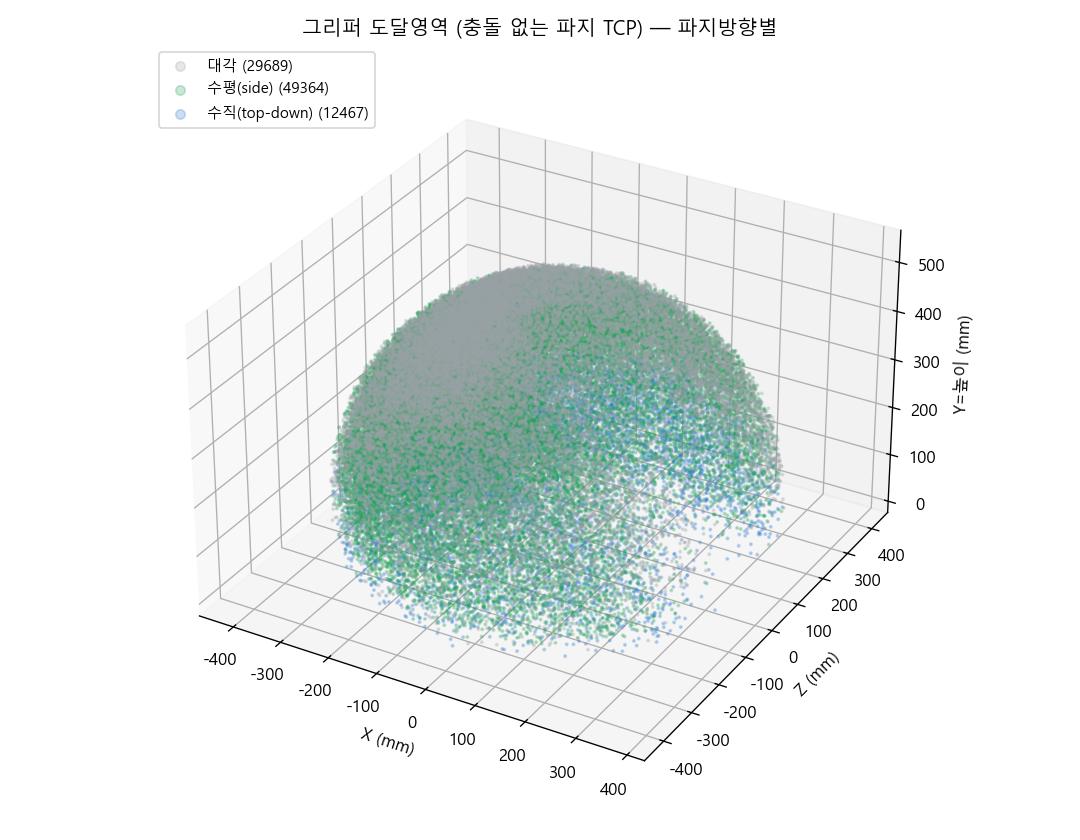
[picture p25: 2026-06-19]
docs/image/grasp-reach3d.png

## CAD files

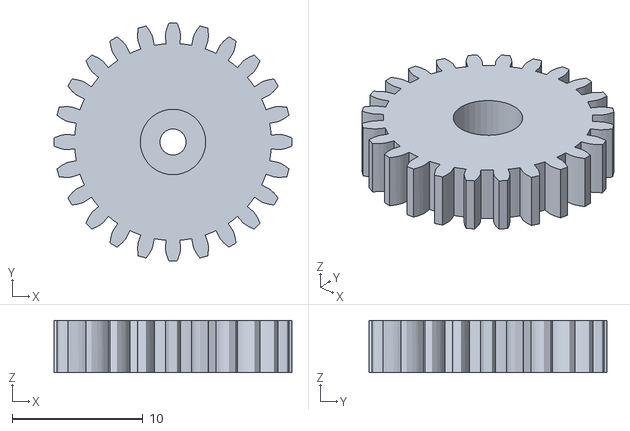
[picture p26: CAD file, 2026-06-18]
laptop/cad/g.stl
18.2 x 18.2 x 4.00

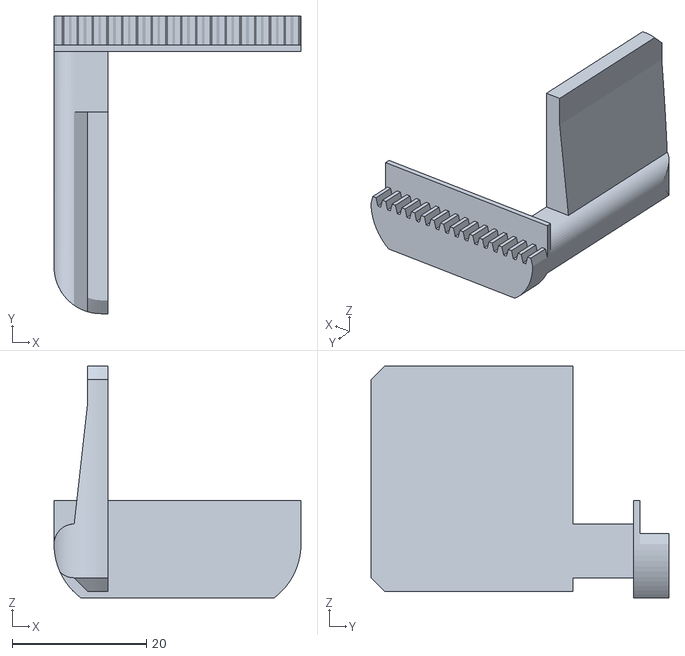
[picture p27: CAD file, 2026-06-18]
laptop/cad/f.1.stl
36.7 x 44.2 x 34.5

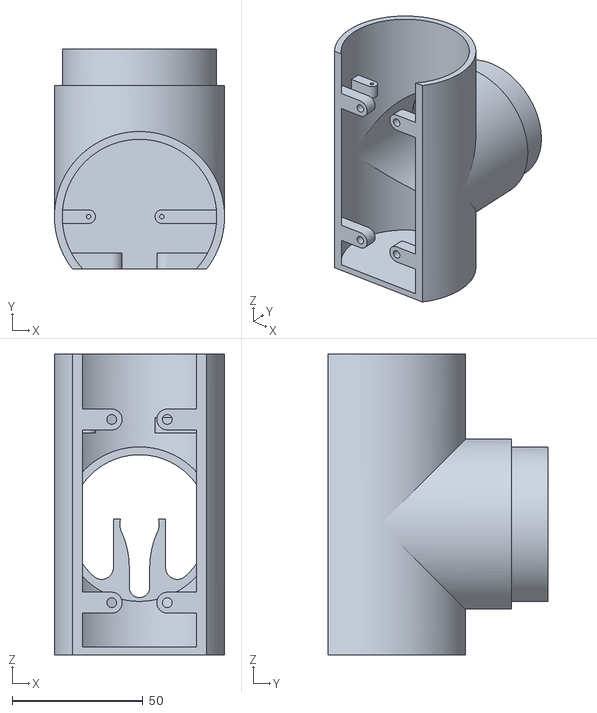
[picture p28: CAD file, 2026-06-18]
laptop/cad/ee.stl
65.0 x 84.0 x 115.0

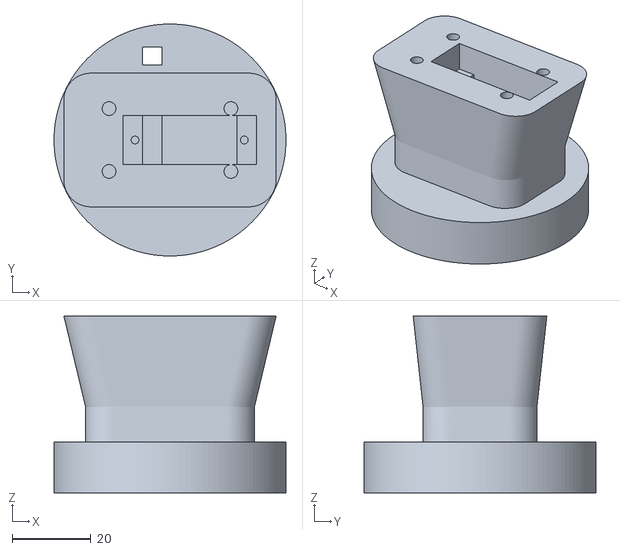
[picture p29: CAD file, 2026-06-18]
laptop/cad/b.stl
59.0 x 59.0 x 45.0

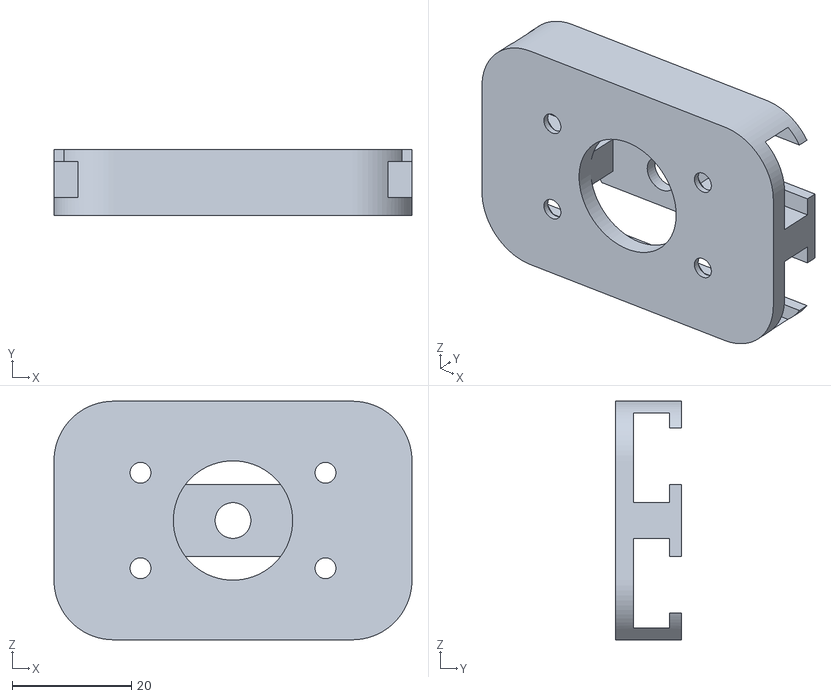
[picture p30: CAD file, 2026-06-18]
laptop/cad/r.stl
60.0 x 11.0 x 40.0

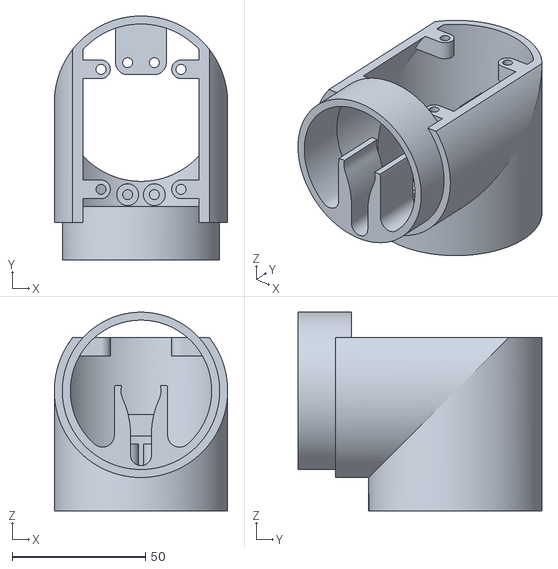
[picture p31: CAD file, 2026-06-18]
laptop/cad/w.stl
65.0 x 91.5 x 74.5

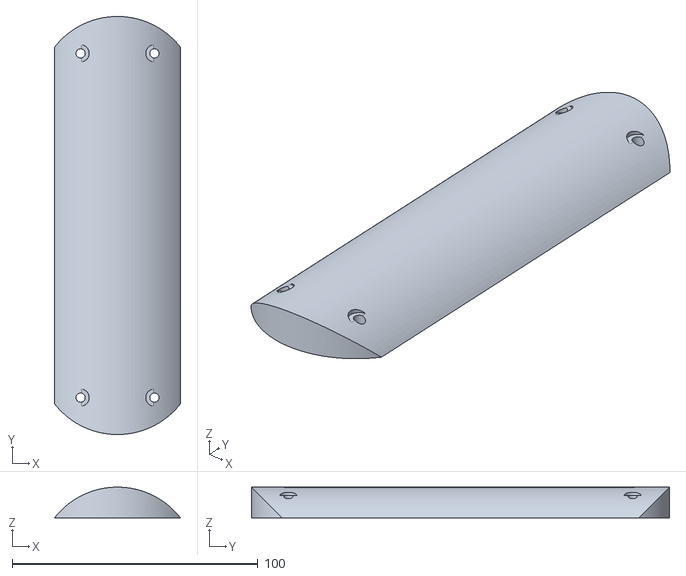
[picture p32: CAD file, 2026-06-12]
laptop/cad/elbow.t.1.stl
51.2 x 170.0 x 12.5

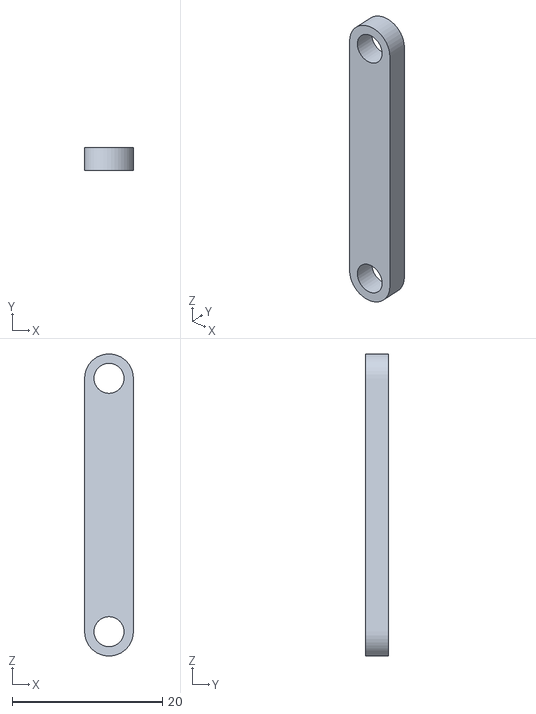
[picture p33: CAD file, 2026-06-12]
laptop/cad/tuas.stl
6.50 x 3.00 x 40.2

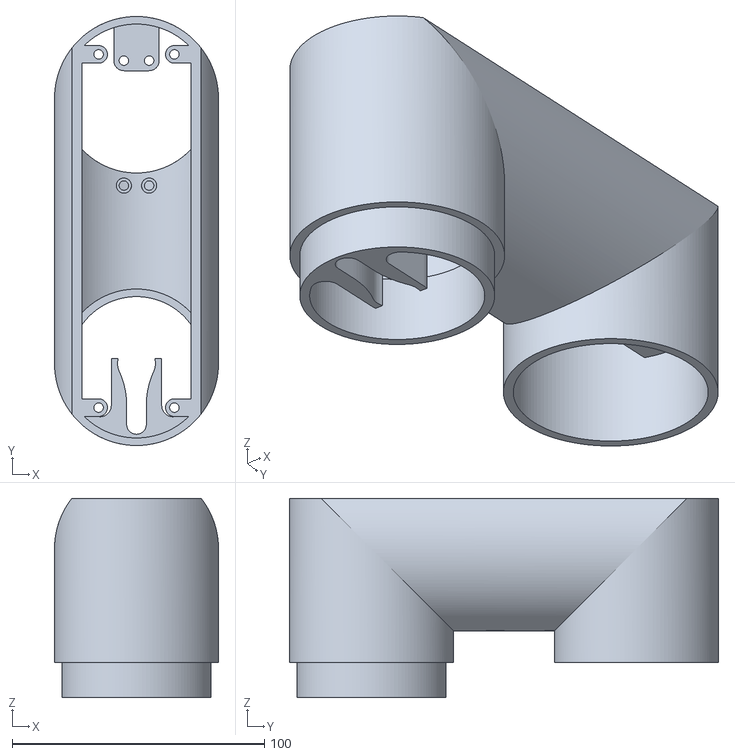
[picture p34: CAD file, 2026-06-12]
laptop/cad/elbow.b.1.stl
65.0 x 170.0 x 79.0

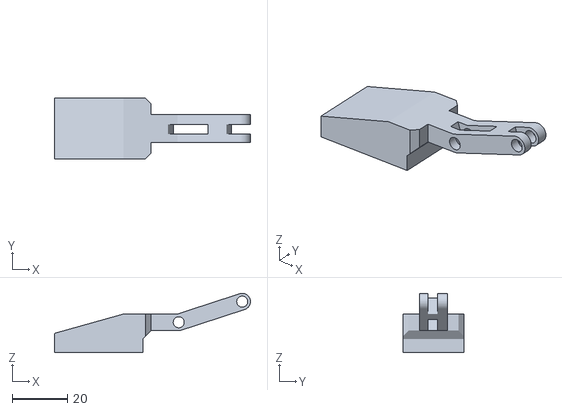
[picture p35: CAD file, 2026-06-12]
laptop/cad/gripper1.stl
71.0 x 22.0 x 21.5

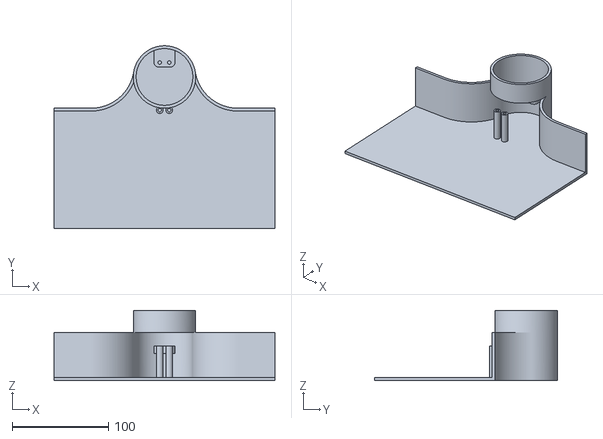
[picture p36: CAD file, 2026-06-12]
laptop/cad/base.stl
230.0 x 190.0 x 73.0

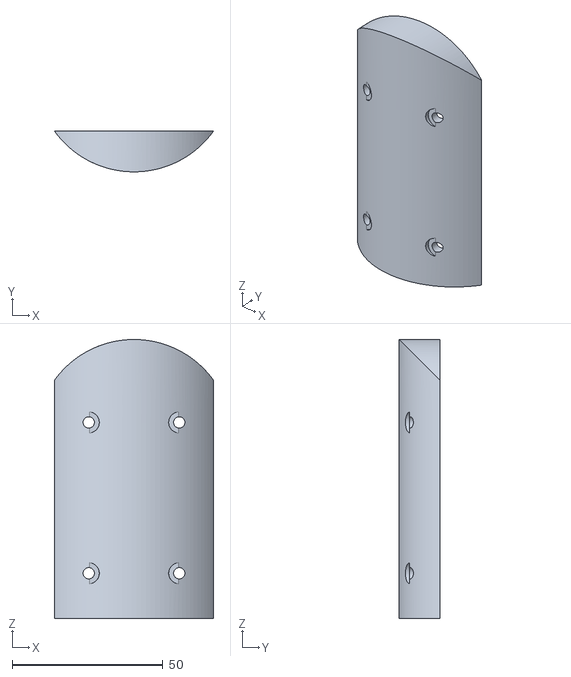
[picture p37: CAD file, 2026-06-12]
laptop/cad/shoulder.b.stl
52.7 x 13.5 x 92.5

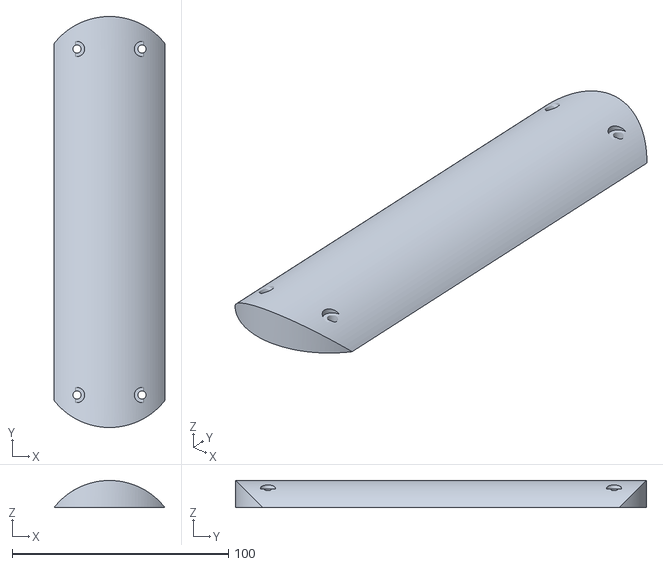
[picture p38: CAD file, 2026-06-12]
laptop/cad/elbow.t.stl
51.2 x 190.0 x 12.5

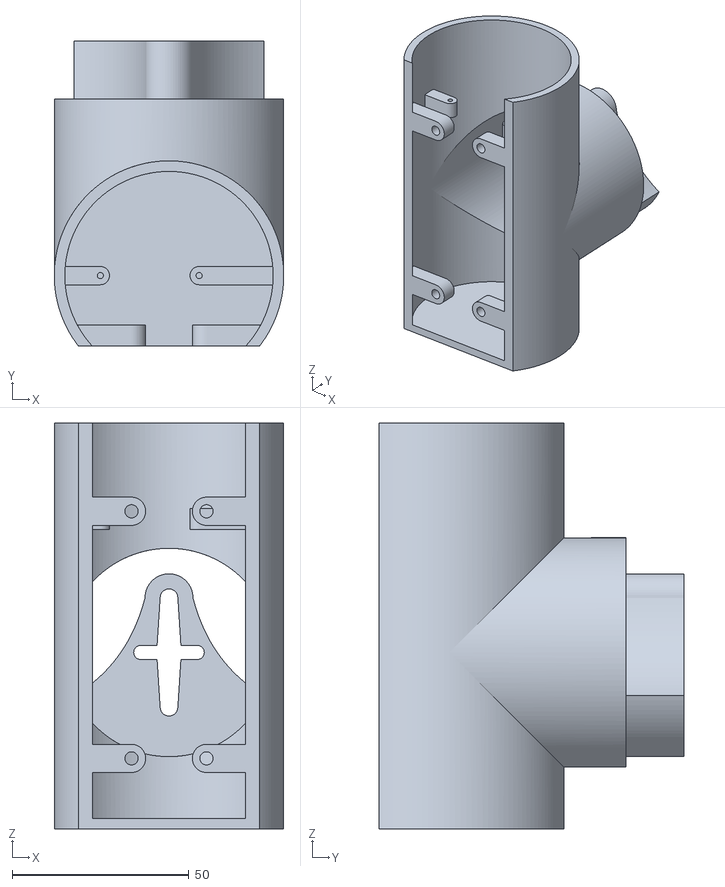
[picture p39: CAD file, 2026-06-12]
laptop/cad/endeffecter.b.stl
65.0 x 86.5 x 115.0

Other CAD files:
laptop/cad/gripper base.stl
laptop/cad/elbow.b.stl
laptop/cad/endeffecter.t.stl
laptop/cad/gear.1.stl
laptop/cad/gear.stl
laptop/cad/shoulder.t.stl
laptop/cad/wrist.b.stl
laptop/cad/wrist.t.stl

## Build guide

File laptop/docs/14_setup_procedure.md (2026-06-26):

# 초기 셋업 절차 — 캘리브레이션 + 로봇 위치 파악 (6단계)

> 작업 환경 **최초 세팅 시 1회** 수행. 핵심 원칙: **카메라를 먼저 고정·보정한 뒤 로봇을 설치**한다.
> (①②③은 로봇 없이 → 로봇 설치 → ④⑤⑥). 각 단계 상세 수식은 [3_coordinate_3d_pipeline.md](3_coordinate_3d_pipeline.md) 참조.

---

## 사전 준비물

- **ChArUco 보드** 인쇄(`calibration/calibration_targets.pdf` 1쪽), 평판에 평평히 부착 — 아래 보드(DICT_5X5_100, 6×8칸)를 **100% 배율**로 출력

ChArUco 보드 — 100%로 인쇄해 평판에 부착(사각 30mm·마커 23mm)

> 🎬 데모 영상 — ChArUco 촬영: [①](https://drive.google.com/file/d/1Vn4H3W7XyQx7gDIsGqlCTaZhZLj_LL9r/view?usp=sharing) · [②](https://drive.google.com/file/d/1bMQTdBhah7Y777o8GNDhDxKxGlNs9XDX/view?usp=sharing)
- **로봇 마커** 인쇄(`calibration/arm_markers.pdf`): 베이스 id0(70mm), 추적 id1~12(40mm) — [15_aruco_markers.md](15_aruco_markers.md)
- **카메라 2대**: 서로 리지드하게 고정(같은 프레임 권장), 작업면에서 **0.5~0.9m**, 대각선 위에서 내려다보게

---

## 순서 개요

```
[카메라 고정·겨냥]
   → ① ChArUco 촬영  → ② 카메라 캘리브레이션  → ③ 3D 검증   (로봇 없이)
   → [로봇 설치]
   → ④ 베이스 마커 부착  → ⑤ 카메라→로봇 변환 T  → ⑥ 관절/작업공간 파악
```

---

## 6단계

### 1단계 — 카메라 배치 & ChArUco 촬영
- **목적:** 캘리브레이션 입력 데이터 확보.
- **할 일:** 카메라를 **로봇이 놓일 자리**를 겨냥해 고정(이후 이동 금지). 로봇 없이 ChArUco 보드를 그 작업 볼륨에서 **위치·기울기(30~45°)·거리**를 바꿔가며 **20~30쌍** 촬영. (도구: 캘리브레이션 페이지의 촬영 기능)
- **완료 기준:** 양쪽 양호 **25쌍 이상**, 화면 가장자리까지 커버리지 양호, 기울임 포즈 포함.

### 2단계 — 카메라 캘리브레이션 산출
- **목적:** 내부(K·왜곡) + 스테레오(R·T) 파라미터.
- **할 일:** `calibration/calibrate_stereo.py` 실행.
- **완료 기준:** 내부/스테레오 **재투영오차 < 1px**, 베이스라인이 실제 카메라 간격과 일치 → `stereo_calib.npz` 저장. (현재값: 0.44/0.49/0.60px, 588mm)

### 3단계 — 3D 정확도 검증
- **목적:** 삼각측량이 실제 mm를 맞히는지 확인.
- **할 일:** `calibration/validate_triangulation.py` 실행 (보드 30mm 칸 복원 오차 측정).
- **완료 기준:** **거리 오차 < ~2mm, 스케일 ≈ 1.0**. (현재값: 0.32mm, 0.9998) → 여기까지 통과하면 **카메라 3D 파이프라인 완성**.

### 4단계 — 로봇팔 배치 & 베이스 마커 부착
- **목적:** 로봇을 작업 위치에 설치하고 기준 마커 부착.
- **할 일:** 1단계에서 겨냥했던 자리에 로봇 설치. **움직이지 않는 베이스**에 **id0(70mm)** 부착, **양 카메라에 보이게**. 팔은 **홈(접은) 자세**로 두어 베이스 마커를 안 가리게.
- **완료 기준:** 양 카메라가 id0 마커를 안정적으로 검출.

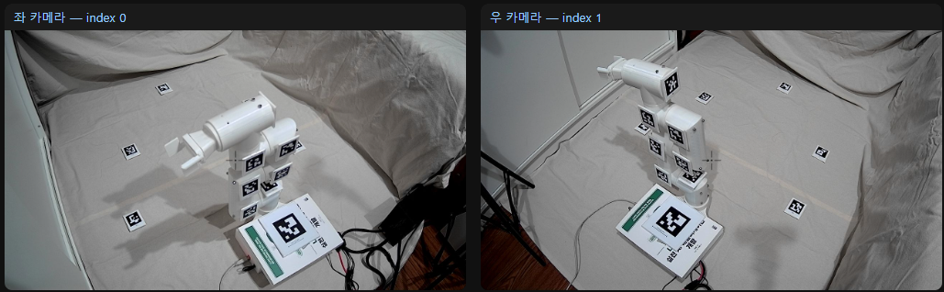
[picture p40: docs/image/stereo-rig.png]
좌·우 카메라가 동시에 로봇팔(베이스 id0 + 링크 마커)을 보는 스테레오 셋업


### 5단계 — 카메라→로봇 변환 T (움직이지 않는 부분)  ✅ 구현
- **목적:** 카메라 좌표 → **로봇 베이스 좌표** (IK가 쓰는 기준).
- **할 일:** 2페이지 4단계에서 id0가 **좌·우 동시 검출**(✓)되는지 확인 → 5단계 **[변환 T 산출]** 클릭.
  - 내부: 양 카메라로 id0 네 코너를 **삼각측량** → 마커 평면으로 로봇 기준 프레임 정의 → `T`(4×4) 저장(`calibration/camera_robot_T.npz`). 마커 변 길이가 70mm 근접인지로 sanity 체크.
- **완료 기준:** T 저장 후 **1페이지 3D 좌표가 로봇 기준 mm**(`frame:"robot"`)로 표시됨.
- 모듈: `armvision/markers.py`(DICT_6X6_250 검출 + T), `stereo3d.py`(T 적용).

### 6단계 — 로봇 관절 위치 파악 (움직이는 부분) + 작업공간
- **목적:** 각 링크/그리퍼 위치 추적의 토대 + 작업공간 범위 확정.
- **할 일:** 추적 마커 **id1~**로 각 링크/그리퍼 포즈 측정(콜드스타트 운동학 보정 토대), 도달 가능 **작업공간 x/y/z 범위** 기록.
- **완료 기준:** 관절 위치·작업공간 정보 확보 → "현재 작업 환경 기본 정보" 확정.
- *(구현 예정 — 추적 마커 부착 후)*

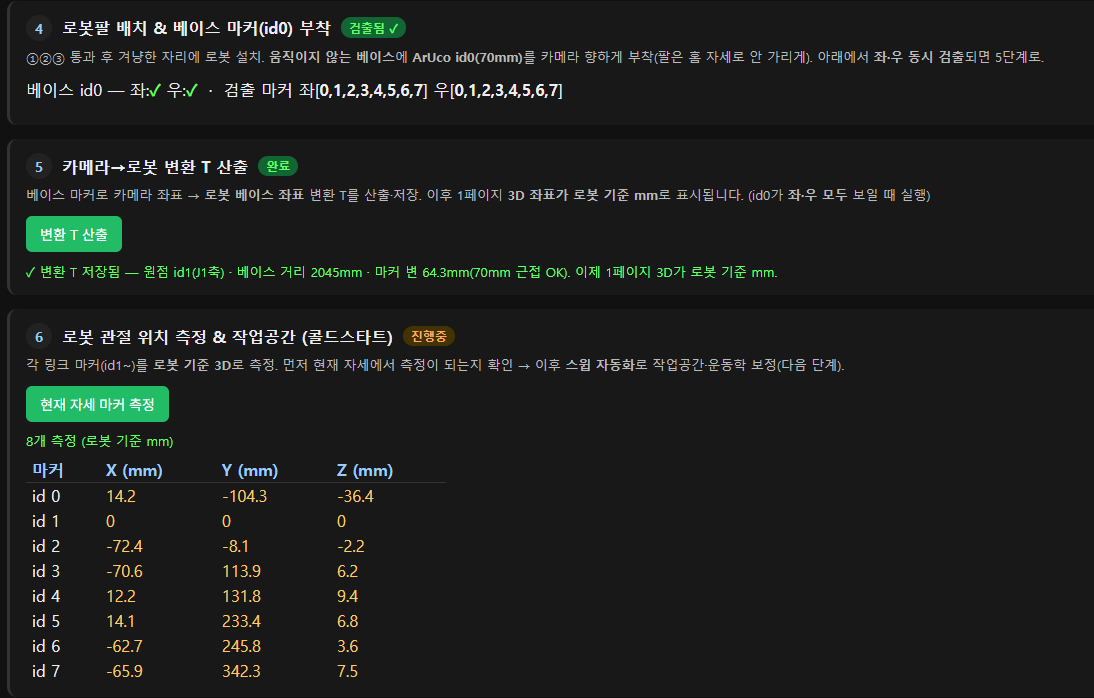
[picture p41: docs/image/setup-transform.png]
2페이지 위저드 4~6단계 — 베이스 id0 검출 → 변환 T 산출(원점=id1 J1축, 마커변 70mm 근접) → 각 마커(id0~) 로봇기준 3D(mm) 측정


---

## 재수행 기준

| 무엇이 바뀌면 | 다시 할 단계 |
|---|---|
| 두 카메라가 서로 움직임 | ① ② ③ (그리고 ⑤) |
| 카메라↔로봇 상대위치 변경 | ⑤ (필요시 ⑥) |
| 렌즈 초점/줌 변경 | ① 부터 |
| 로봇만 살짝 이동 | ⑤ ⑥ |

> 한 번 통과하면 결과(`stereo_calib.npz`, T 등)를 저장해 재사용. 위 변화가 없으면 매번 할 필요 없음.

**새 환경으로 다시 보정:** 2페이지의 **🔄 새 환경으로 초기화** 버튼 → 기존 촬영본·캘리브레이션을 타임스탬프 폴더(`captures/_archive_*`, `calibration/_archive/`)로 **보관**하고 0부터 다시 시작한다(삭제 아님, 복구 가능). 보정 완료 전까지 1페이지 3D 좌표는 비활성.

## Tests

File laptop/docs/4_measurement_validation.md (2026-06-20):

# 측정 검증 — 마커 3D 측정의 강체 운동학 일관성

> **요지:** 스테레오 카메라 + ChArUco 캘리브레이션 + ArUco 마커 + 카메라→로봇 변환(T)으로 측정한
> 로봇팔 마커의 3D 좌표가, **실제 강체 운동학(rigid-body kinematics)과 정량적으로 일치**함을 보인다.
> 즉 본 비전 측정 파이프라인이 **물리적으로 정확**하며, 이후 시각-운동학 자가보정(콜드스타트)의
> 신뢰할 수 있는 입력이 됨을 **두 차례 독립 실행(24·30자세)** 의 실측으로 입증한다.

관련: [3_coordinate_3d_pipeline.md](3_coordinate_3d_pipeline.md) · [8_arm3d_simulator.md](8_arm3d_simulator.md) · [15_aruco_markers.md](15_aruco_markers.md)

---

## 1. 측정 파이프라인

```
좌·우 카메라 ──ArUco(DICT_6X6_250) 검출──▶ 마커 코너(2D)
   │  ChArUco 스테레오 캘리브레이션(K,d,R,T,P1,P2)
   ▼
삼각측량 ──▶ 코너 3D(좌 카메라 좌표, mm) ──평균──▶ 마커 중심
   │  카메라→로봇 변환 T (id0 방향 + id1=J1축 원점)
   ▼
마커 3D (로봇 베이스 기준 mm)
```
- 좌표계: **원점 = id1(J1 회전축), 방향 = id0(고정 베이스 마커)**.
- 도구: `armvision/markers.py`(검출·T·측정), `armvision/stereo3d.py`(삼각측량), `calibration/analyze_validation.py`(통계·그래프).
- 거리: 카메라 ≈ 1.4 m. 마커: id0 70 mm, id1~ 40 mm.
- 마커 배치: 링크당 2개 쌍 — (id1,id2) 베이스 링크, (id3,id4) 링크2, (id5,id6) 링크3, id7 말단.

---

## 2. 실험 설계 — 체계적 단일관절 스윕

가설을 **검증 가능한 운동학 명제**로 만들기 위해, 4페이지 `검증 시퀀스`가 자동으로 다음을 수행한다
(모터를 **하나씩만** 움직이고 매 사이클 기준자세로 복귀 → 동시구동에 의한 브라운아웃 방지):

| 구간 | 내용 | 검증 대상 |
|---|---|---|
| **반복성** | 기준자세(J190·J2 0·J3 90·J4 90·J5 180)에서 N회 반복 측정 | 측정 잡음 바닥 (§3.1) |
| **J1 스윕** | J1 = 50·65·80·95·110·125° | 베이스 회전축 복원 (§3.3) |
| **J3·J4 스윕** | 각 60·75·105·120·135° | 피치 축 복원·강체 거리 (§3.2~3.3) |
| **J5·J2 스윕** | J5 0·60·120°, J2 20·40° | 추가 자유도 일관성 |

**두 차례 독립 실행**으로 수집(카메라 재배치 사이에 측정):

| 실행 | 자세 수 | 반복성 횟수 | 수집일 |
|:--:|:--:|:--:|:--:|
| Run 1 | 24 | 10 | 2026-06 |
| Run 2 | 30 | 9 | 2026-06 |

> 데이터: `measure_data.csv`(Run 1), `measure_data (1).csv`(Run 2). CSV 형식 `idx,J1..J6,id0_x..id7_z`.

---

## 3. 분석 & 결과

운동학의 세 불변량으로 측정 정확성을 정량화한다. 그래프는 `analyze_validation.py`가 자동 생성.

### 3.1 측정 반복성 — 잡음 바닥 (repeatability)

기준자세를 동일하게 반복 측정했을 때 마커별 3D 위치 표준편차 σ.

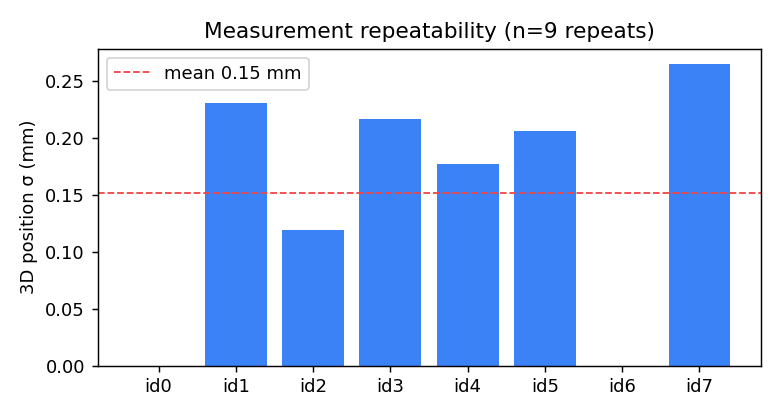
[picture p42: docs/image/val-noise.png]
반복성


| 실행 | 평균 σ | 최대 σ | 반복 |
|:--:|:--:|:--:|:--:|
| Run 1 | 0.06 mm | **0.32 mm** | 10회 |
| Run 2 | — | **0.26 mm** | 9회 |

→ 카메라 **1.4 m** 거리에서 측정 잡음이 **서브-밀리미터(≤ 0.3 mm)**. 이 값이 이후 모든 비교의 분해능 바닥이다.

### 3.2 강체 거리 보존 (rigid-body invariant)

같은 링크 위 두 마커의 거리는 **어떤 관절 운동에도 일정**해야 한다. 전 자세에서 마커쌍 거리를 측정:

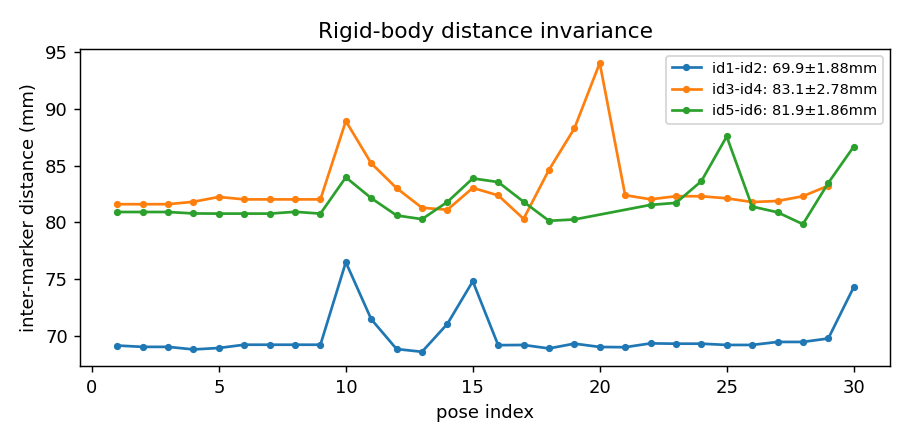
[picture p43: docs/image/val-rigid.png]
강체 거리


| 마커쌍 | Run 1 (평균±σ) | Run 2 (평균±σ) | 교차 일치 |
|---|:--:|:--:|:--:|
| id1 ↔ id2 (베이스 링크) | 69.9 ± 2.40 mm | **69.9 ± 1.88 mm** | **완전 일치** |
| id3 ↔ id4 (링크2) | 82.2 ± 1.59 mm | 83.1 ± 2.78 mm | 0.9 mm |
| id5 ↔ id6 (링크3) | 81.8 ± 2.04 mm | 81.9 ± 1.86 mm | 0.1 mm |

→ 강체 거리가 **표준편차 ≈ 2 mm**로 보존되고, **두 독립 실행의 평균이 0.1~0.9 mm 이내로 재현**된다.
특히 id1-id2 거리는 양쪽 실행에서 **69.9 mm로 동일** — 측정 파이프라인이 자세·시점과 무관하게 기하를 일관되게 복원함을 직접 입증.

### 3.3 관절 축 복원 (motion ⇒ axis)

한 관절만 단독 회전시키면, 그 위의 마커는 **고정 축을 중심으로 한 원**을 그려야 한다.
SVD 평면 피팅 + Kasa 원 피팅으로 궤적을 복원:

**J1(베이스 회전) — 말단 마커 id7:**

| 2D 평면 피팅 | 3D 공간 (회전축선 포함) |
|:--:|:--:|
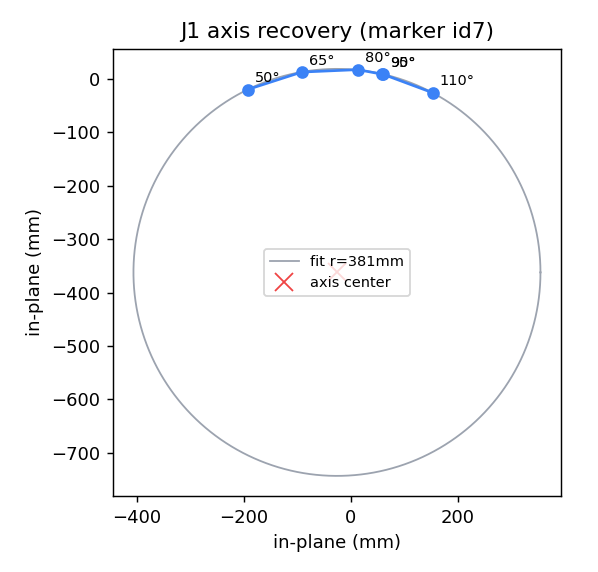
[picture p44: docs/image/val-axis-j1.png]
J1축 2D
|  | J1축 3D |

| 실행 | 각도 수 | 복원 반경 |
|:--:|:--:|:--:|
| Run 1 | 5 (60~120°) | **377 mm** |
| Run 2 | 6 (50~125°) | **381 mm** |

→ 말단이 그리는 원의 반경이 **377 mm vs 381 mm로 1% 이내 일치**. 회전축(수직)도 동일하게 복원된다.
서로 다른 날·서로 다른 각도 집합에서 같은 물리량이 나온다는 것은 **측정이 우연이 아닌 실제 강체 운동을 포착**함을 의미.

**기타 관절(Run 2):** J4(피치) 단독 회전 시 id6가 반경 **159 mm** 원호, J3·J2도 각자의 축에 대한 원호로 복원
(축에서 가까운 마커일수록 반경이 작아 SNR이 낮음 → 축에서 먼 말단 마커가 가장 선명).

---

## 4. 3차원 시각화

측정 데이터를 3D 그래프로 직접 제시 (`analyze_validation.py` 자동 생성).

**(a) 작업공간 마커 점군** — 전 자세의 8개 마커 3D 위치. id0(원점)~id7(말단)이 베이스→말단 순으로 층을 이루며, 같은 마커가 자세에 따라 일관된 영역에 분포.

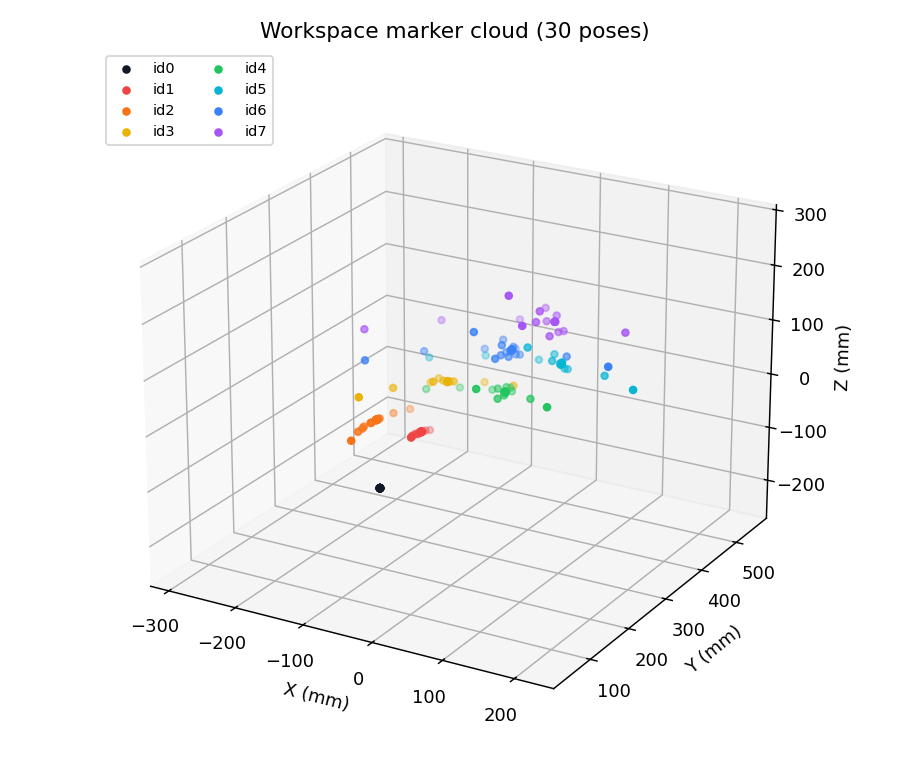
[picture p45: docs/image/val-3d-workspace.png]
작업공간 점군


**(b) 팔 골격** — 대표 자세별로 링크쌍 중점을 이은 팔 형상. 단일관절 변화가 말단 위치를 어떻게 바꾸는지 3D로 표현.

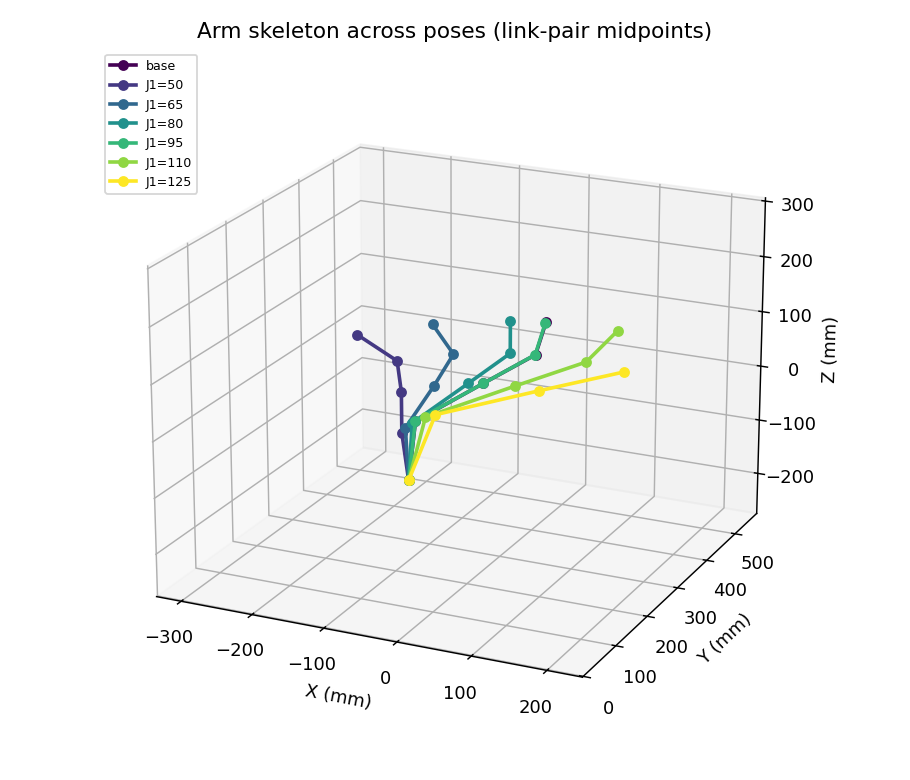
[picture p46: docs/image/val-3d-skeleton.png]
팔 골격


> J1 축 복원의 3D 버전은 §3.3 우측 그림 참조 — 말단 궤적 원 + 복원된 수직 회전축선.

---

## 5. 정량 요약

| 지표 | 값 | 의미 |
|---|----|---|
| 측정 반복성(σ) | **≤ 0.3 mm** (Run1 0.32 / Run2 0.26) | 잡음 바닥 |
| 강체 거리 보존(σ) | **≈ 2 mm** | 기하 일관성 |
| 강체 거리 교차실행 일치 | **0.1 ~ 0.9 mm** | 재현성 |
| J1 회전반경 교차실행 일치 | **377 vs 381 mm (1%)** | 운동학 정합·재현성 |
| 자세 다양성 | 24 + 30 = **54자세**, 6관절 중 5관절 단독 스윕 | 검증 폭 |

스테레오 캘리브레이션 기준: 재투영오차 ~0.5 px, 베이스라인 588 mm, 보드 30 mm를 0.32 mm 오차로 복원(→ [3_coordinate_3d_pipeline.md](3_coordinate_3d_pipeline.md)).

---

## 6. 학술적 의의

1. **비전 측정의 물리적 타당성 입증** — "측정 반복성", "강체 거리 보존", "관절 축 복원"이라는 **검증 가능한 운동학 명제**로 측정 정확성을 정량화. 단순 재투영오차(2D)가 아니라 **3D 강체 운동학과의 일치**를 보인 점이 핵심.
2. **재현성** — 서로 다른 날·각도 집합의 두 독립 실행이 핵심 물리량(강체거리·회전반경)을 **1% 이내로 재현**. 단발 측정의 우연이 아님을 통계적으로 배제.
3. **시각-운동학 자가보정의 토대** — 측정이 ±2 mm 수준의 강체 일관성을 가지므로, 측정값과 FK 예측의 차이는 곧 **운동학 모델 오차(3D 프린트 누적)** 로 귀속 가능 → 콜드스타트 DH 최적화의 신뢰할 수 있는 관측치가 된다.
4. **저비용 외부 계측** — 표준 웹캠 2대 + 인쇄 마커로 1.4 m 거리에서 서브-mm 반복성·mm 강체일관성을 달성, 별도 고가 트래커 없이 운동학 검증이 가능함을 보였다.

---

## 7. 한계

- **절대 스케일 ~수 %**: id0 마커 변 측정 75 mm(실측 70 mm) — 1.4 m 거리·가장자리 커버리지 부족에 기인. 작업 거리(0.5~0.9 m)에서 재보정 시 개선.
- **원거리 마커 분산**: 말단(id7) 등 축에서 먼 마커는 같은 각오차가 위치오차로 증폭(반경 추정엔 유리하나 절대위치 분산↑).
- **자세 의존 누락**: 극단 자세(J3 135°, J5 롤)에서 일부 마커가 가려져 측정 누락(occlusion) — 정상적 한계, 다른 자세로 보완.
- **J6 미검증**: 손목 롤(J6)은 단독 마커가 축과 가까워 별도 자세 설계 필요.

---

## 8. 재현 방법

1. 2페이지에서 캘리브레이션(①②③) 완료 → id0 부착 → ⑤ 변환 T 산출(원점=id1).
2. 4페이지 `검증 시퀀스` 실행 → 자동 스윕 → 자세별 마커 3D를 CSV로 다운로드.
3. `python calibration/analyze_validation.py <csv경로>` → §3·§4의 모든 통계·2D/3D 그래프를 `docs/image/`에 일괄 생성.

> 데이터·분석값은 2026-06 실측 기준(Run 1·2). 환경(카메라 배치) 변경 시 재측정.

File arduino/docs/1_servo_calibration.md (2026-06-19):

# 서보 캘리브레이션 — 펄스 ↔ 각도 매핑

> 각 관절 서보의 **0° / 180° 펄스 폭(µs)** 을 실측해 기록한다.
> 서보 개체마다 펄스↔각도 규격이 다르므로 **관절별로 따로 측정**한다.
> 측정 도구: `arduino/src/main.cpp` 서보 테스트 스케치 (시리얼 명령 `u <ch> <us>` 로 직접 펄스 인가).

---

## 1. 공통 사항

| 항목 | 값 |
|---|-----|
| PWM 드라이버 | PCA9685 (I2C 0x40, 12bit) |
| PWM 주파수 | 50Hz (주기 20000µs) |
| 제어 방식 | PCA9685 레지스터 직접 제어 (Wire), 1카운트 ≈ 4.88µs |
| 카운트 변환 | `count = us × 4096 / 20000` |

### 채널 ↔ 관절 매핑

| PCA9685 채널 | 관절 |
|:---:|---|
| 0 | J1 (base) |
| 1 | J2 (shoulder) |
| 2 | J3 (elbow) |
| 3 | J4 (wrist_pitch) |
| 4 | J5 (wrist_roll) |
| 5 | J6 (gripper_rot) |
| 6 | J7 (gripper, 개폐) |

---

## 2. 서보 특성 (중요)

이 서보는 **기구적 끝단(hard stop)이 없는 마그네틱(절대 위치) 엔코더 서보**로 확인됨.

- **무전원 시:** 손으로 돌리면 끝 스톱 없이 무한 회전 (기어 손상 아님, 정상).
- **전원 인가 시:** 엔코더가 절대 각도를 읽어 명령 펄스 위치로 복귀(폐루프 위치 제어).
- **함의 ① — 소프트웨어 한계 필수:** 물리적으로 막는 게 없으므로, 관절 한계를 **반드시 코드에서 제한**해야 한다 (한계 초과 시 자기 구조물 충돌·배선 꼬임 위험).
- **함의 ② — 전원 인가 시 큰 스윙 위험:** 전원을 넣으면 명령/엔코더 위치로 복귀하며 **큰 호를 그릴 수 있음** → 안전한 부팅/홈 복귀 전략 필요.
- 펄스를 펄스범위 이상으로 키우면 어느 지점에서 **포화(더 안 움직임)** 된다 → 그 지점이 실질 상한.

---

## 3. 관절별 캘리브레이션 표

| 관절 | 채널 | 0° 펄스(µs) | 180° 펄스(µs) | 가동폭(µs) | µs/°  | 상태 |
|:---:|:---:|:---:|:---:|:---:|:---:|:---:|
| **J1** | 0 | **600** | **2740** | 2140 | ≈ 11.89 | ✅ 확정 |
| **J2** | 1 | **530** | **2670** | 2140 | ≈ 11.89 | ✅ 확정 |
| **J3** | 2 | **520** | **2700** | 2180 | ≈ 12.11 | ✅ 확정 |
| **J4** | 3 | **690** | **2800** | 2110 | ≈ 11.72 | ✅ 확정 |
| **J5** | 4 | **620** | **2750** | 2130 | ≈ 11.83 | ✅ 확정 |
| **J6** | 5 | **560** | **2700** | 2140 | ≈ 11.89 | ✅ 확정 |
| J7 | 6 | — | — | — | — | ⬜ 미장착 (그리퍼 없음) |

> 참고: J7(그리퍼 개폐)은 각도가 아니라 open/close 두 위치로 쓸 수 있음 — 측정 시 별도 표기.

---

## 4. 펄스 ↔ 각도 변환식

관절별 `us_0`(0°), `us_180`(180°)를 측정한 뒤:

```
us    = us_0 + (angle_deg / 180) × (us_180 − us_0)
angle = (us − us_0) × 180 / (us_180 − us_0)
```

예) J1, angle = 90° → `600 + (90/180)×(2740−600) = 600 + 1070 = 1670µs`

---

## 5. 측정 절차 (관절 1개 기준)

1. 해당 채널을 중간 펄스로 보내 응답·매핑 확인 (`u <ch> 1500`).
2. 한쪽 끝으로 천천히 이동시켜 **0° 위치의 펄스**를 미세 조정으로 확정.
3. 반대쪽 끝으로 이동시켜 **180° 위치의 펄스**를 확정.
4. 끝 스톱이 없으므로 **포화(더 안 움직이는) 지점**도 함께 기록.
5. 본 표에 기입.

---

## 6. TODO

- [x] J1~J6 0°/180° 펄스 측정 (완료)
- [ ] J7(그리퍼) 장착 후 측정
- [ ] 측정된 매핑을 펌웨어 상수(`pin_config.h` 또는 캘리브레이션 테이블)로 반영
- [ ] 관절별 소프트웨어 안전 한계(min/max 펄스) 확정 → docs/6_conventions.md 관절 한계와 동기화
- [ ] 안전한 전원 인가/홈 복귀 시퀀스 정의

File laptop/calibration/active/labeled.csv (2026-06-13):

J1 | J2 | J3 | J4 | J5 | J6 | floor_clear_mm | self_clear_mm | self_target | collision
90 | 98.8 | 128.7 | 108.5 | 98.1 | 76.3 | 50.0 | 29.3 | wrist.b.stl | 0
90 | 116.3 | 78.8 | 160.5 | 173.5 | 69 | 50.0 | 25.7 | wrist.b.stl | 0
90 | 142.5 | 95.2 | 102.2 | 166.6 | 12.8 | 50.0 | 25.2 | wrist.b.stl | 0
90 | 15.7 | 3.6 | 149.9 | 140.1 | 156.6 | 50.0 | 26.0 | wrist.b.stl | 0
90 | 176.2 | 143.8 | 83.1 | 140.5 | 21.3 | 50.0 | 21.5 | wrist.b.stl | 0
90 | 115.2 | 25.8 | 170 | 93.9 | 74.6 | 50.0 | 30.2 | wrist.b.stl | 0
90 | 47.6 | 139.4 | 82.1 | 102.3 | 3.4 | 50.0 | 29.5 | wrist.b.stl | 0
90 | 111.2 | 110.2 | 111 | 169.9 | 122.7 | 50.0 | 24.3 | wrist.b.stl | 0
90 | 64.7 | 78.7 | 125.6 | 10.8 | 120 | 50.0 | 24.3 | wrist.b.stl | 0
90 | 120.7 | 37.9 | 23.2 | 56.8 | 65.5 | 50.0 | 28.8 | wrist.b.stl | 0
90 | 102.6 | 78.9 | 177.9 | 18.4 | 37.6 | 50.0 | 18.1 | elbow.b.stl | 0
90 | 29 | 117.6 | 45.6 | 83.9 | 44 | 50.0 | 32.5 | wrist.b.stl | 0
90 | 28.6 | 19.9 | 118.1 | 24.9 | 35.4 | 50.0 | 26.3 | wrist.b.stl | 0
90 | 66.4 | 147.8 | 17.5 | 150.8 | 17.3 | 50.0 | 22.8 | wrist.b.stl | 0
90 | 175.8 | 84.4 | 175.8 | 108.9 | 133.1 | 21.0 | 32.2 | wrist.b.stl | 0
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

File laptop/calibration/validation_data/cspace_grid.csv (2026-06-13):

J1 | J2 | J3 | J4 | J5 | J6 | floor_clear_mm | self_clear_mm | self_target | collision
90 | 0 | 0 | 0 | 90 | 90 | 50.0 | 30.1 | wrist.b.stl | 0
90 | 0 | 0 | 5 | 90 | 90 | 50.0 | 30.1 | wrist.b.stl | 0
90 | 0 | 0 | 10 | 90 | 90 | 50.0 | 30.1 | wrist.b.stl | 0
90 | 0 | 0 | 15 | 90 | 90 | 50.0 | 30.1 | wrist.b.stl | 0
90 | 0 | 0 | 20 | 90 | 90 | 50.0 | 30.1 | wrist.b.stl | 0
90 | 0 | 0 | 25 | 90 | 90 | 50.0 | 30.1 | wrist.b.stl | 0
90 | 0 | 0 | 30 | 90 | 90 | 50.0 | 30.1 | wrist.b.stl | 0
90 | 0 | 0 | 35 | 90 | 90 | 50.0 | 30.1 | wrist.b.stl | 0
90 | 0 | 0 | 40 | 90 | 90 | 50.0 | 30.1 | wrist.b.stl | 0
90 | 0 | 0 | 45 | 90 | 90 | 50.0 | 30.1 | wrist.b.stl | 0
90 | 0 | 0 | 50 | 90 | 90 | 50.0 | 30.1 | wrist.b.stl | 0
90 | 0 | 0 | 55 | 90 | 90 | 50.0 | 30.1 | wrist.b.stl | 0
90 | 0 | 0 | 60 | 90 | 90 | 50.0 | 30.1 | wrist.b.stl | 0
90 | 0 | 0 | 65 | 90 | 90 | 50.0 | 30.1 | wrist.b.stl | 0
90 | 0 | 0 | 70 | 90 | 90 | 50.0 | 30.1 | wrist.b.stl | 0
90 | 0 | 0 | 75 | 90 | 90 | 50.0 | 30.1 | wrist.b.stl | 0
90 | 0 | 0 | 80 | 90 | 90 | 50.0 | 30.1 | wrist.b.stl | 0
90 | 0 | 0 | 85 | 90 | 90 | 50.0 | 30.1 | wrist.b.stl | 0
90 | 0 | 0 | 90 | 90 | 90 | 50.0 | 30.1 | wrist.b.stl | 0
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

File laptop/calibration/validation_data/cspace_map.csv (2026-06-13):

J2 | J3 | J4 | floor_clear_mm | self_clear_mm | self_target | collision
0 | 0 | 0 | 50.0 | 30.1 | wrist.b.stl | 0
0 | 0 | 5 | 50.0 | 30.1 | wrist.b.stl | 0
0 | 0 | 10 | 50.0 | 30.1 | wrist.b.stl | 0
0 | 0 | 15 | 50.0 | 30.1 | wrist.b.stl | 0
0 | 0 | 20 | 50.0 | 30.1 | wrist.b.stl | 0
0 | 0 | 25 | 50.0 | 30.1 | wrist.b.stl | 0
0 | 0 | 30 | 50.0 | 30.1 | wrist.b.stl | 0
0 | 0 | 35 | 50.0 | 30.1 | wrist.b.stl | 0
0 | 0 | 40 | 50.0 | 30.1 | wrist.b.stl | 0
0 | 0 | 45 | 50.0 | 30.1 | wrist.b.stl | 0
0 | 0 | 50 | 50.0 | 30.1 | wrist.b.stl | 0
0 | 0 | 55 | 50.0 | 30.1 | wrist.b.stl | 0
0 | 0 | 60 | 50.0 | 30.1 | wrist.b.stl | 0
0 | 0 | 65 | 50.0 | 30.1 | wrist.b.stl | 0
0 | 0 | 70 | 50.0 | 30.1 | wrist.b.stl | 0
0 | 0 | 75 | 50.0 | 30.1 | wrist.b.stl | 0
0 | 0 | 80 | 50.0 | 30.1 | wrist.b.stl | 0
0 | 0 | 85 | 50.0 | 30.1 | wrist.b.stl | 0
0 | 0 | 90 | 50.0 | 30.1 | wrist.b.stl | 0
0 | 0 | 95 | 50.0 | 30.1 | wrist.b.stl | 0
0 | 0 | 100 | 50.0 | 30.1 | wrist.b.stl | 0
0 | 0 | 105 | 50.0 | 30.1 | wrist.b.stl | 0
0 | 0 | 110 | 50.0 | 30.1 | wrist.b.stl | 0
0 | 0 | 115 | 50.0 | 30.1 | wrist.b.stl | 0
0 | 0 | 120 | 50.0 | 30.1 | wrist.b.stl | 0
0 | 0 | 125 | 50.0 | 30.1 | wrist.b.stl | 0
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

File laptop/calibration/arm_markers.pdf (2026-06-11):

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

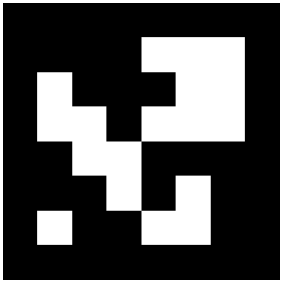
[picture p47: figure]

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

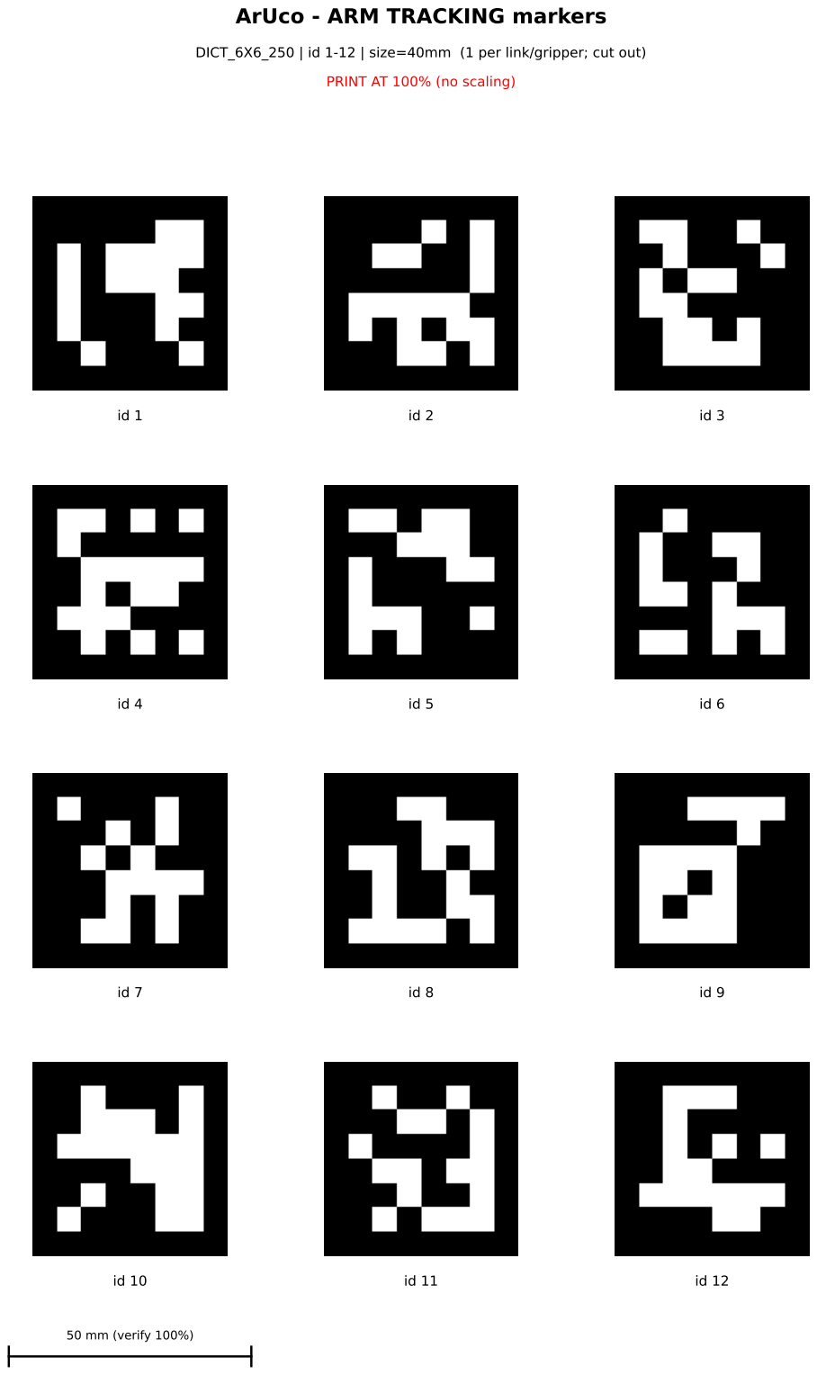
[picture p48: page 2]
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

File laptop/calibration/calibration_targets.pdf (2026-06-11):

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

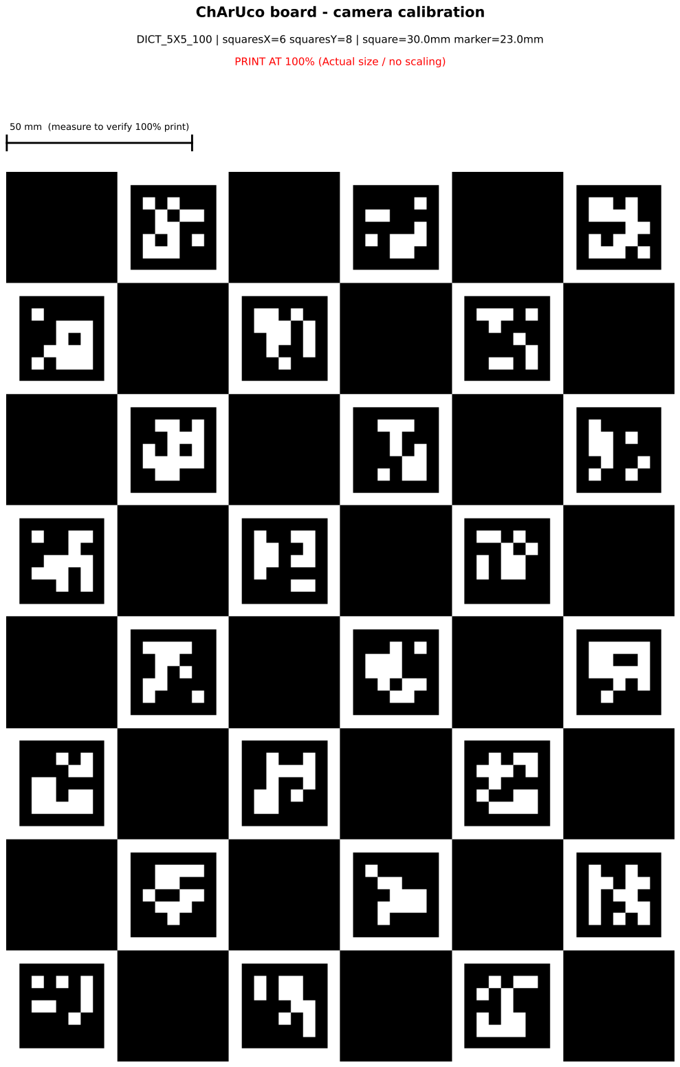
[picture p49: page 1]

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

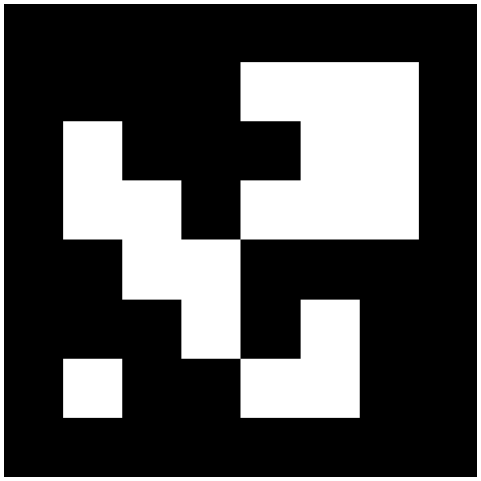
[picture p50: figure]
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

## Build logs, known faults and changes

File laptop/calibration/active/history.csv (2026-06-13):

round | n_labeled | accuracy | recall
1 | 2000 | 0.9751 | 0.9199
2 | 3500 | 0.9849 | 0.9399
3 | 5000 | 0.9888 | 0.9758
4 | 6500 | 0.9908 | 0.9749

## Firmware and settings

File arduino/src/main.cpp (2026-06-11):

/**
 * 서보 구동 검증 스케치 — 채널별 1개씩 각도 제어 / 스윕
 *
 * 목적: PCA9685 채널에 연결된 서보가 각도 명령에 따라 움직이는지 1개씩 확인.
 *       채널 ↔ 관절(J1~J7) 매핑도 함께 검증.
 *
 * 안전:
 *   - 부팅 직후 모든 채널 PWM OFF(무신호) → 서보는 가만히 있음(limp).
 *   - 명령을 받은 채널만 움직인다. 스윕은 느리게(2°/25ms) 진행.
 *   - 각도 범위는 설계 범위인 1000~2000us(= test 0~180)로 보수적으로 제한.
 *     이상음(버징)·정지(스톨) 발생 시 즉시 SMPS 전원 차단.
 *
 * 시리얼 명령 (115200, 줄 단위):
 *   a <ch> <angle>   채널 ch 를 angle(0~180)로 1회 이동
 *   s <ch>           채널 ch 느린 스윕 (90→0→90→180→90)
 *   n <ch>           채널 ch 중립(90)
 *   r <ch>           채널 ch 무신호(limp, 힘 풀기)
 *   r all            전체 채널 무신호
 *
 * 참고: docs/serial_protocol.md, docs/conventions.md (PWM 매핑)
 */
#include <Arduino.h>
#include <Wire.h>

static const uint8_t PCA = 0x40;
#define REG_MODE1     0x00
#define REG_PRESCALE  0xFE
#define REG_LED0_ON_L 0x06
static const uint8_t NUM_CH = 16;

static void writeReg(uint8_t reg, uint8_t val) {
  Wire.beginTransmission(PCA);
  Wire.write(reg);
  Wire.write(val);
  Wire.endTransmission();
}

static uint8_t readReg(uint8_t reg) {
  Wire.beginTransmission(PCA);
  Wire.write(reg);
  Wire.endTransmission();
  Wire.requestFrom(PCA, (uint8_t)1);
  return Wire.read();
}

static void pcaSetFreq(float freq) {
  float prescaleval = 25000000.0f / (4096.0f * freq) - 1.0f;
  uint8_t prescale = (uint8_t)floor(prescaleval + 0.5f);
  writeReg(REG_MODE1, 0x00);            // 리셋: SLEEP 비트 해제(깨움)
  delay(5);
  writeReg(REG_MODE1, 0x10);            // SLEEP=1 (prescale 변경에 필요)
  writeReg(REG_PRESCALE, prescale);
  writeReg(REG_MODE1, 0x00);            // SLEEP=0 (오실레이터 가동)
  delay(5);
  writeReg(REG_MODE1, 0xA0);            // RESTART + auto-increment, SLEEP=0
}

static void pcaSetPWM(uint8_t ch, uint16_t on, uint16_t off) {
  Wire.beginTransmission(PCA);
  Wire.write(REG_LED0_ON_L + 4 * ch);
  Wire.write(on & 0xFF);
  Wire.write(on >> 8);
  Wire.write(off & 0xFF);
  Wire.write(off >> 8);
  Wire.endTransmission();
}

// 50Hz, 주기 20000us, 12bit(4096)
static uint16_t usToCount(uint16_t us) {
  return (uint16_t)((uint32_t)us * 4096 / 20000);
}

// test 각도 0~180 → 1000~2000us (설계 범위, 보수적)
static uint16_t angleToUs(int angle) {
  if (angle < 0) angle = 0;
  if (angle > 180) angle = 180;
  return (uint16_t)(1000 + (uint32_t)angle * 1000 / 180);
}

static void setAngle(uint8_t ch, int angle) {
  pcaSetPWM(ch, 0, usToCount(angleToUs(angle)));
}

static void releaseCh(uint8_t ch) {
  pcaSetPWM(ch, 0, 0);  // 무신호 → limp
}

static void slowMove(uint8_t ch, int from, int to) {
  int step = (to >= from) ? 2 : -2;
  for (int a = from; (step > 0) ? (a <= to) : (a >= to); a += step) {
    setAngle(ch, a);
    if (a % 30 == 0) { Serial.print(F("  ch")); Serial.print(ch); Serial.print(F(" -> ")); Serial.print(a); Serial.println(F(" deg")); }
    delay(25);
  }
}

// --- 와이드 범위(500~2500us, 270deg 서보 가정) 테스트 ---
// 펄스↔각도 캘리브레이션용으로 클램프를 넓게 둠(끝 스톱 없는 엔코더 서보 탐색).
// 50Hz 주기 20000us 이내라면 PCA9685는 출력 가능. 단, 양 끝은 천천히 접근할 것.
static const int US_MIN = 300;
static const int US_MAX = 4000;
static void setUs(uint8_t ch, int us) {
  if (us < US_MIN) us = US_MIN;
  if (us > US_MAX) us = US_MAX;
  pcaSetPWM(ch, 0, usToCount((uint16_t)us));
}

static void slowMoveUs(uint8_t ch, int from, int to) {
  int step = (to >= from) ? 20 : -20;
  for (int u = from; (step > 0) ? (u <= to) : (u >= to); u += step) {
    setUs(ch, u);
    if (u % 200 < 20) { Serial.print(F("  ch")); Serial.print(ch); Serial.print(F(" -> ")); Serial.print(u); Serial.println(F(" us")); }
    delay(30);
  }
}

static void wideSweep(uint8_t ch) {
  Serial.print(F("[wide] ch")); Serial.print(ch); Serial.println(F(" 중앙(1500us)으로 이동"));
  setUs(ch, 1500); delay(700);
  Serial.println(F("[wide] -> 2500us 방향(천천히)"));
  slowMoveUs(ch, 1500, 2500);
  slowMoveUs(ch, 2500, 1500);
  Serial.println(F("[wide] -> 500us 방향(천천히)"));
  slowMoveUs(ch, 1500, 500);
  slowMoveUs(ch, 500, 1500);
  Serial.print(F("[wide] ch")); Serial.print(ch); Serial.println(F(" 완료 (중앙 유지)"));
}

static void sweep(uint8_t ch) {
  Serial.print(F("[sweep] ch")); Serial.print(ch); Serial.println(F(" 시작: 중립(90)으로 이동"));
  setAngle(ch, 90); delay(600);
  slowMove(ch, 90, 0);
  slowMove(ch, 0, 90);
  slowMove(ch, 90, 180);
  slowMove(ch, 180, 90);
  Serial.print(F("[sweep] ch")); Serial.print(ch); Serial.println(F(" 완료 (중립 유지)"));
}

void setup() {
  Serial.begin(115200);
  delay(200);
  Wire.begin();
  pcaSetFreq(50.0f);
  for (uint8_t c = 0; c < NUM_CH; c++) releaseCh(c);  // 전 채널 무신호로 시작

  Serial.println();
  Serial.println(F("=== 서보 구동 검증 준비 완료 (전 채널 무신호) ==="));
  Serial.println(F("명령: 'a <ch> <ang>' | 's <ch>' | 'n <ch>' | 'r <ch>' | 'r all'"));
}

void loop() {
  static char buf[24];
  static uint8_t idx = 0;
  while (Serial.available()) {
    char c = Serial.read();
    if (c == '\n' || c == '\r') {
      if (idx == 0) continue;
      buf[idx] = '\0';
      idx = 0;
      // 파싱
      char cmd = buf[0];
      if (cmd == 'r' && buf[1] == ' ' && buf[2] == 'a') {
        for (uint8_t c2 = 0; c2 < NUM_CH; c2++) releaseCh(c2);
        Serial.println(F("[ok] 전 채널 무신호(limp)"));
      } else {
        char *p = buf + 1;
        while (*p == ' ') p++;
        int ch = atoi(p);                 // 첫 숫자 = 채널
        char *q = strchr(p, ' ');         // 두 번째 숫자 = 각도(있으면)
        int ang = q ? atoi(q + 1) : -1;
        bool hasAng = (q != NULL);
        if (ch < 0 || ch >= NUM_CH) { Serial.println(F("[err] ch 범위(0~15)")); }
        else if (cmd == 'a' && hasAng) { setAngle(ch, ang); Serial.print(F("[ok] a ch")); Serial.print(ch); Serial.print(F(" -> ")); Serial.print(ang); Serial.println(F(" deg")); }
        else if (cmd == 's') { sweep(ch); }
        else if (cmd == 'w') { wideSweep(ch); }
        else if (cmd == 'u' && hasAng) { setUs(ch, ang); Serial.print(F("[ok] u ch")); Serial.print(ch); Serial.print(F(" -> ")); Serial.print(ang); Serial.println(F(" us")); }
        else if (cmd == 'n') { setAngle(ch, 90); Serial.print(F("[ok] n ch")); Serial.print(ch); Serial.println(F(" -> 90")); }
        else if (cmd == 'r') { releaseCh(ch); Serial.print(F("[ok] r ch")); Serial.print(ch); Serial.println(F(" limp")); }
        else { Serial.println(F("[err] 알 수 없는 명령")); }
      }
    } else if (idx < sizeof(buf) - 1) {
      buf[idx++] = c;
    }
  }
}

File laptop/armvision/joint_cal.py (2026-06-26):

"""
관절 보정 스윕 — 안전 영역 정의 + 스윕 자세 생성 (트랙 2).

실측 안전·가시성 박스 (사용자 확인 2026-06-21):
- J5 = 180° 고정 (모든 ArUco 보임), J6·J7 고정 (J6 ArUco 없음)
- J2 ∈ [25, 70]   (25°↓ 바닥 쓸림: id7이 지면 ~220–250mm / 70°↑ 마커 가림)
- J3 범위는 J2에 의존:      J2=25 → [20,120],  J2=70 → [60,160]   (선형 보간)
- J4 범위는 (J2,J3)에 의존 (양선형 보간, 4코너):
    (J2,J3)=(70,60)→[0,90], (70,160)→[80,170], (25,20)→[0,90], (25,120)→[90,180]
- J1 은 스윕(수직축이라 중력 sag 없음·백래시/게인 확인용) — 좌·우 FOV 제한은
  실제 스윕에서 마커 미검출 샘플을 건너뛰어 처리(여기선 후보 범위만).

안쪽으로 MARGIN(°) 여유를 둬 절대 한계를 절대 안 건드린다.
이 모듈은 순수 함수(하드웨어/카메라 무관) — 단위 테스트 가능.
"""

J2_MIN, J2_MAX = 25.0, 70.0
J5_FIXED = 180.0
J6_FIXED = 90.0
J1_RANGE = (60.0, 120.0)   # 후보 스윕 범위(미검출 샘플은 실 스윕에서 skip)
MARGIN = 4.0               # 한계 안쪽 여유(°)


def _lerp(a, b, t):
    return a + (b - a) * t


def _f2(j2):
    return (min(J2_MAX, max(J2_MIN, j2)) - J2_MIN) / (J2_MAX - J2_MIN)   # 0@25 .. 1@70


def j3_bounds(j2):
    """J2에서 J3 [lo, hi] (margin 미적용 원시 한계)."""
    f = _f2(j2)
    return _lerp(20.0, 60.0, f), _lerp(120.0, 160.0, f)


def j4_bounds(j2, j3):
    """(J2,J3)에서 J4 [lo, hi] — J3는 자기 범위 내 비율로 정규화 후 양선형 보간."""
    f2 = _f2(j2)
    lo3, hi3 = j3_bounds(j2)
    f3 = 0.0 if hi3 <= lo3 else (min(hi3, max(lo3, j3)) - lo3) / (hi3 - lo3)
    j4_lo = f3 * ((1 - f2) * 90.0 + f2 * 80.0)
    j4_hi = (1 - f3) * 90.0 + f3 * ((1 - f2) * 180.0 + f2 * 170.0)
    return j4_lo, j4_hi


def _safe_range(lo, hi, m=MARGIN):
    """안쪽 여유 적용. 너무 좁으면 중앙 한 점."""
    a, b = lo + m, hi - m
    if a > b:
        mid = (lo + hi) / 2.0
        return mid, mid
    return a, b


def safe_j3(j2):
    return _safe_range(*j3_bounds(j2))


def safe_j4(j2, j3):
    return _safe_range(*j4_bounds(j2, j3))


def is_safe(j1, j2, j3, j4):
    """명령 자세가 안전 영역(여유 포함) 안인가 — 실 구동 직전 최종 가드."""
    if not (J2_MIN + MARGIN - 1e-6 <= j2 <= J2_MAX - MARGIN + 1e-6):
        return False
    lo3, hi3 = safe_j3(j2)
    if not (lo3 - 1e-6 <= j3 <= hi3 + 1e-6):
        return False
    lo4, hi4 = safe_j4(j2, j3)
    if not (lo4 - 1e-6 <= j4 <= hi4 + 1e-6):
        return False
    if not (0.0 <= j1 <= 180.0):
        return False
    return True


def _grid(lo, hi, n):
    if n <= 1 or hi <= lo:
        return [round((lo + hi) / 2.0, 1)]
    return [round(lo + (hi - lo) * i / (n - 1), 1) for i in range(n)]


def generate_sweep(n2=4, n3=4, n4=3, n1=3, j1_range=J1_RANGE):
    """안전 영역을 격자로 훑는 스윕 자세 목록 생성. 각 항목 {J1..J6}. is_safe 통과분만."""
    js1 = _grid(j1_range[0], j1_range[1], n1)
    poses = []
    for j2 in _grid(J2_MIN + MARGIN, J2_MAX - MARGIN, n2):   # 여유 적용 범위에서 격자
        lo3, hi3 = safe_j3(j2)
        for j3 in _grid(lo3, hi3, n3):
            lo4, hi4 = safe_j4(j2, j3)
            for j4 in _grid(lo4, hi4, n4):
                for j1 in js1:
                    if is_safe(j1, j2, j3, j4):
                        poses.append({"J1": j1, "J2": j2, "J3": j3, "J4": j4,
                                      "J5": J5_FIXED, "J6": J6_FIXED})
    return poses


SAFE_HOME = {"J1": 90.0, "J2": 45.0, "J3": 80.0, "J4": 90.0, "J5": J5_FIXED, "J6": J6_FIXED}   # 스윕 시작 전 권장 안전 자세(박스 내)

_J1234 = ("J1", "J2", "J3", "J4")


def transition_order(cur, tgt):
    """cur(안전)→tgt(안전)를 '단일 관절 이동'들의 순서로. 모든 중간 full-config가 안전한
    순서를 반환(없으면 None=그 자세 skip). 단일 관절 이동은 양 끝이 안전하면 경로 전체 안전
    (관절별 안전집합=구간)이라, 끝 자세만 is_safe로 검사하면 충분."""
    from itertools import permutations
    diff = [j for j in _J1234 if abs(cur.get(j, 0.0) - tgt[j]) > 0.05]
    if not diff:
        return []
    base = {**cur, "J5": J5_FIXED, "J6": J6_FIXED}
    for perm in permutations(diff):
        c = dict(base); seq = []; ok = True
        for j in perm:
            c2 = dict(c); c2[j] = tgt[j]
            if not is_safe(c2["J1"], c2["J2"], c2["J3"], c2["J4"]):
                ok = False; break
            seq.append((j, tgt[j])); c = c2
        if ok:
            return seq
    return None


def single_joint_sweep(n_per=7):
    """관절별 단일 스윕(한 관절만 n_per점, 나머지 고정) — 깨끗한 k 추출용.
    중력 sag 자세 의존(B) 위해 J2·J3·J4는 다른 관절을 몇 설정으로 바꿔가며 반복.
    is_safe 통과분만. 각 블록은 '나머지 관절이 같은' 부분스윕이라 원호 적합이 안정적."""
    out = []

    def add(joint, lo, hi, fixed):
        for v in _grid(lo, hi, n_per):
            p = {**SAFE_HOME, **fixed, joint: round(v, 1)}
            if is_safe(p["J1"], p["J2"], p["J3"], p["J4"]):
                out.append(p)

    for fx in ({"J2": 45, "J3": 80, "J4": 90}, {"J2": 35, "J3": 60, "J4": 70}):   # J1 (수직축)
        add("J1", J1_RANGE[0], J1_RANGE[1], fx)
    for (j3, j4) in ((80, 90), (60, 70), (110, 110)):                              # J2 (자세 의존)
        add("J2", J2_MIN + MARGIN, J2_MAX - MARGIN, {"J3": j3, "J4": j4})
    for j2 in (45, 60):                                                            # J3
        lo, hi = safe_j3(j2); add("J3", lo, hi, {"J2": j2, "J4": 90})
    for (j2, j3) in ((45, 80), (60, 120)):                                         # J4
        lo, hi = safe_j4(j2, j3); add("J4", lo, hi, {"J2": j2, "J3": j3})
    return out


def plan_summary(n_per=7):
    """스윕 계획 요약(움직임 없음·미리보기용) — 단일 관절 스윕."""
    poses = single_joint_sweep(n_per)
    def rng(key):
        vs = [p[key] for p in poses]
        return [min(vs), max(vs)] if vs else [None, None]
    # 어떤 관절이 변하는 블록인지 카운트(나머지 고정 기준)
    return {
        "count": len(poses),
        "ranges": {k: rng(k) for k in ("J1", "J2", "J3", "J4")},
        "fixed": {"J5": J5_FIXED, "J6": J6_FIXED},
        "n_per": n_per, "mode": "single-joint", "margin_deg": MARGIN,
        "sample": poses[:8],
    }


if __name__ == "__main__":   # 자가 검증 (하드웨어 없이)
    # 1) 코너가 실측값을 재현하나
    assert abs(j3_bounds(25)[0] - 20) < 1e-9 and abs(j3_bounds(25)[1] - 120) < 1e-9
    assert abs(j3_bounds(70)[0] - 60) < 1e-9 and abs(j3_bounds(70)[1] - 160) < 1e-9
    for (j2, j3, lo, hi) in [(70, 60, 0, 90), (70, 160, 80, 170), (25, 20, 0, 90), (25, 120, 90, 180)]:
        b = j4_bounds(j2, j3)
        assert abs(b[0] - lo) < 1e-9 and abs(b[1] - hi) < 1e-9, (j2, j3, b)
    print("[corners] OK — 실측 코너 재현")
    # 2) 생성된 모든 자세가 안전한가
    poses = generate_sweep()
    assert all(is_safe(p["J1"], p["J2"], p["J3"], p["J4"]) for p in poses)
    print(f"[sweep] {len(poses)}자세 · 모두 안전영역 내 OK")
    import json
    print(json.dumps(plan_summary(), ensure_ascii=False, indent=1))

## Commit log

2026-05-20 docs: 프로젝트 폴더 구조 및 기능 명세 정비
    3계층(ai_server/laptop/arduino) 폴더와 공통 docs 추가.
    - 공통 docs: 마스터 사양, 아키텍처, gRPC/Serial/DSL 인터페이스, 규약
    - 컴포넌트별 docs: 각 계층 기능 명세
    - README 정비 및 .gitignore 추가
2026-05-20 docs: README에 기술 스택 섹션 추가
    badge 표 스타일로 핵심 AI/ML · 제어/통신/하드웨어 · 협업 스택 정리.
    내용은 기존 docs/사양서 기준(Whisper, Gemma 4, RF-DETR, Arduino, gRPC 등).
2026-06-11 laptop: Django 비전 파이프라인 + arduino 펌웨어/캘리브레이션
    - arduino: PlatformIO 프로젝트(PCA9685 서보 테스트), J1~J6 펄스 캘리브레이션 문서
    - laptop: Django 3페이지(카메라·탐지 / 캘리브레이션 위저드 / 자연어 제어 골격)
    - vision: YOLO-World 객체탐지(GPU) + 객체 id, ChArUco 스테레오 캘리브레이션 + 삼각측량 3D
    - 캘리브레이션 타깃 / 로봇 ArUco 마커 PDF 생성기
    - docs: 좌표 파이프라인·셋업 절차·모델 선택·마커 스킴
2026-06-11 docs: 실제 구현에 맞게 문서 정합화
    - 객체 탐지 RF-DETR → YOLO-World (README/system_spec/architecture/dsl/grpc)
    - 노트북 순수 asyncio → Django, Python 3.12 (laptop README, 구조/의존성/문서목록 갱신)
    - 서보: 끝 스톱 없는 마그네틱 엔코더형 + 관절별 실측 펄스(0~180°) 주의 노트 + servo_calibration 링크
    - J5 서보 DS3218 Pro → MG90S (conventions, arduino README)
    - README 현재 상태를 실제 진행(조립·서보 캘리브레이션·Django 비전 파이프라인)으로 갱신
2026-06-11 feat(laptop): 3D 로봇팔 제어 페이지(4) + 웹앱 기능명세 + 문서 정리
    - arm3d 페이지: Three.js 3D 로봇팔(DH 치수 근사, C-브래킷 코봇) — 관절 클릭→슬라이더→3D 회전, 360° 뷰 (3D-only, 실물 연동 예정)
    - web_app.md: Django 4페이지 + 엔드포인트 기능명세 신규
    - laptop/docs/README: 3→4 페이지, web_app 링크
    - arduino/docs/README: 현재 테스트 펌웨어=ASCII 명령(이진 패킷은 목표) 노트
    - README 현재 상태: 4페이지 웹 UI(3D 뷰어) 반영
2026-06-12 feat(laptop): STL 3D 시뮬레이터·실물 연동 + 카메라 선택/캘리브레이션 연동
    4페이지(arm3d):
    - STL 부품 직접 조립 → CATIA식 면대면 결합(원통 동심+평면 일치, 가상원통 영역성장)
    - 위치보정(XYZ/roll), 고정 그룹(강체 통째 이동 + 시안 연결선), 저장/불러오기(assembly.json)
    - 조립 반복 시 크기 축소 버그 수정(scale/quaternion 리셋)
    - ③ 제어 모드: 관절 슬라이더 → 3D + 실물 서보 동시 구동
    - arduino_bridge.py(pyserial COM9), 각도→펄스 변환, 기존 `u ch us` 사용(펌웨어 무수정)
    - 속도 제한 2단 램프(기본 10°/s=60°/6초), 정렬도 동일 속도로 천천히
    -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
    [base.stl, elbow.b.1.stl, elbow.b.stl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]
2026-06-12 docs: 계층형 문서 구조 재정리 + 3D 모델링·캘리브레이션 방법 서술
    흐름: 바깥(개요) → 안(상세). 폴더로 들어갈수록 구체화.
    - 컴포넌트 폴더 루트 README 신설: laptop/ arduino/ ai_server/ (개요 + 하위 폴더 지도)
    - docs/README.md 강화: 왜 3계층으로 나눴는지 + 공통 인터페이스 허브
    - 루트 README: 저장소 구조/문서 안내를 계층 흐름에 맞게 갱신
    방법론 추가:
    - arm3d_simulator.md: "참조 설계 → CAD(STL) → 브라우저 조립·리깅" 제작 과정
    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
2026-06-12 docs: 문서 사진을 루트 docs/image/ 로 통일 + 사진 목록(매니페스트) 추가
    - docs/image/README.md: 필요 사진 목록(핵심/기능/보조) + 파일명 규약
    - laptop/docs/assets/ 제거, 사진 자리 placeholder를 docs/image/ 경로로 통일
2026-06-12 docs: 첨부 사진 8장 문서에 연결 (real-arm 제외)
    - 루트 README 대표컷: 참조 설계 + 3D 디지털 트윈
    - arm3d_simulator: 설계도/면대면 결합/6관절 조립(2컷)/제어 UI
    - coordinate_3d_pipeline: ChArUco 코너 검출(calib-result.png)
    - web_app: 1페이지 YOLO 탐지 + 좌표표
    - arduino/docs: 배선도(Mega+PCA9685+ToF+서보+전원)
    - docs/image/README: 보유/미보유 목록 갱신
    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
2026-06-13 fix(arm3d): csClear 줄 끝 잘못 들어간 '/표시' 제거 — 모듈 스크립트 문법오류로 4페이지 전체 작동불가였음
2026-06-13 fix(control): 정렬/이동 속도 — 명령각 기준을 홈(90°)으로
    원인: 서보 위치 피드백이 없어 _cmd(마지막 명령각)를 3D 자세와 같게 초기화하면
    정렬 시 gap=0 → 펄스 한 번에 전송 → 서보가 최고속으로 튐.
    수정:
    - _cmd 초기값을 홈(90°)으로 → 정렬/연동이 홈→목표로 항상 천천히 램프
    - [🏠 홈(90°) 기준] 버튼: 실물을 홈에 둔 뒤 _cmd=90 재설정(재연결/리셋 후에도)
    - 연동 카드 안내: 홈 두기 → 홈 기준 → 정렬/연동 순서 명시
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2026-06-13 fix(control): 검증 시퀀스 — 한 번에 한 모터만 + 사이클(이동→측정→복귀)
    원인: 모터 동시 구동 시 전압강하로 아두이노 리셋 → 시퀀스 꼬임/측정 어긋남.
    - moveJoint(): 한 관절만 이동, 3D 정착 + 실물 서보 도착(1s)까지 대기 → 다음 단계 금지
    - runValidation(): 기준 자세(한 관절씩) → 반복성 10회 → 관절별 단독 사이클
    (기준→목표 측정→기준 복귀), 각 단계 단일 관절만 구동
    - [■ 정지]·끊김 시 즉시 중단
2026-06-13 fix(control): 3D-실물 동기화 깨짐 진단·방지 + 아두이노 리셋 감지
    원인: 아두이노가 전압부족으로 리셋되면 펄스가 안 먹히는데, 3D 램프는
    연결과 무관하게 계속 진행 → 3D만 앞서가고 실물은 멈춤(동기화 깨짐).
    - arduino_bridge: 시리얼 수신에서 펌웨어 부팅 배너 감지 → reset_count, status에 resets
    - rampCtrl: 연동 중엔 연결됐을 때만 3D 전진(실물 못 따라오면 3D도 정지)
    - 연결 끊김/리셋 감지 시: 시퀀스 중단 + 3D 동결 + 경고('전압 부족 의심')
    → 리셋 여부를 화면에서 검증 가능. 떴다면 전원(SMPS·콘덴서·GND) 문제.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
    [arduino_bridge.py]
2026-06-13 fix(control): 실측 서보 펄스 적용(채널별) + 시퀀스 진단 로그
    문제: 조립 모터 기본값(600/2740)을 써서 전 관절 펄스가 1670으로 동일.
    J2를 0°로 보내면 펄스 2740 > J2 실상한 2670 → 서보 포화·과전류 → 리셋 가능.
    - SERVO_CAL: servo_calibration.md 실측값을 채널별로 제어에 적용
    (ch0 600/2740, ch1 530/2670, ch2 520/2700, ch3 690/2800, ch4 620/2750, ch5 560/2700)
    - moveJoint/리셋/끊김 지점 console 로그 — J2 튐 원인 추적용
2026-06-13 fix(arm3d): 관절각 0°가 90°로 렌더되는 falsy 버그 (m.angle||90)
    원인: applyAngles에서 (m.angle||90) — JS에서 0||90=90이라
    J2 등 각도가 0이면 3D가 90으로 렌더 → 실물은 0인데 3D만 90으로 '튐'.
    실물 펄스(angToUs)는 0을 정상 처리했으므로 렌더 전용 버그였음.
    수정: (m.angle==null?90:m.angle) 로 0을 보존.
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2026-06-13 docs: 측정검증 문서 학술등급 업그레이드 + 실측 데이터 2회분
    - measurement_validation.md 전면 개정: 4자세 수기측정 → 체계적 단일관절 스윕
    - Run1(24자세)·Run2(30자세) 두 독립 실행의 실측 통계로 재작성
    - 핵심: 교차실행 재현성(id1-id2 거리 양쪽 69.9mm, J1 반경 377/381mm 1% 일치)
    - 2D/3D 그래프 6종 임베드(반복성·강체거리·축복원·작업공간점군·골격)
    - validation_data/: run1_24pose.csv, run2_30pose.csv 원본 보존(재현용)
    - docs/image: Run2 기준 그래프 재생성
    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
    [run1_24pose.csv, run2_30pose.csv]
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2026-06-13 fix(cspace): 자기충돌 오탐 수정 — 그리퍼 손 그룹화 + 정적부품 제외
    증상: 스윕 결과 전 조합 self_clear=-2.0 상수(100% 충돌) = 그리퍼 내부/정적부품 오탐.
    원인1: 그리퍼가 'gripper base + 손가락/기어 6개'(전부 rev) 한 덩어리인데
    '가장 깊은 부품'만 그리퍼로 봐서 gripper base를 대상에서 못 뺌.
    → 체인이 갈라지는 첫 부품(gripper base)부터 모든 자손을 '손'으로 묶어 출처+제외.
    원인2: 링크의 .t(윗면) 반쪽이 리깅 안 된 정적 루트로 떠 있어, 팔과 따로 놀며 오탐.
    → 자기충돌 대상을 리깅된 체인 부품(+고정 베이스)으로 제한.
    추가: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
2026-06-13 data(cspace): 실측 C-space 충돌 지도 + 히트맵/3D (L0 산출물)
    4페이지 C-space 스윕(J2·J3·J4 0~180°, 5°격자, 50653조합) 결과:
    - 자기충돌 0% (그리퍼 구성상 모든 자세에서 최소 27.6mm 여유 — 사진과 일치)
    - 바닥충돌 6.5% (마진15 반영 8.1%): J2≈0(앞으로 접음)·J2≈180(뒤로 넘김)+극단 J3
    - J2 70~110(수직)에선 전 영역 안전 — 팔이 위를 향해 바닥 무관
    - 위험영역이 2개 날개로 분리되는 전형적 C-space 장애물 형상
    cspace_analysis.py로 J2슬라이스 히트맵(충돌경계 등고선)+3D 산점 생성.
    [cspace_map.csv]
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2026-06-13 feat(cspace): 랜덤(J2~J6) 스윕 추가 + 학습기 관절 자동감지
    발견(축 분석): J1=[0,-1,0] 완전 수직 → 높이·거리 불변 → 충돌 무관(고정 정당).
    J5≈수직(자기충돌 영향), J6=[-1,0,0] 수평피치 → 그리퍼를 바닥으로 내림(바닥 핵심).
    기존 스윕은 J6 고정이라 '그리퍼가 바닥 닿는' 핵심 관절을 빠뜨렸음.
    - 스윕 CSV에 J1~J6 전 관절각 기록(격자/랜덤 호환)
    - 격자(J2·J3·J4) + 랜덤(J2~J6 Monte Carlo, N개) 두 모드. J1은 항상 고정.
    → 5D는 격자 폭발(37^5)이라 랜덤 샘플링이 정석.
    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
    [cspace_grid.csv]
2026-06-13 data(cspace): 5D 랜덤 C-space + 학습 모델 (J2~J6)
    랜덤 스윕 40000샘플(J2~J6 무작위, J1 고정):
    - 충돌 10.0% (격자 6.5% → 상승): J6 피치로 그리퍼 바닥도달, J5/J6로 새 위험영역
    - 자기충돌 0% → 1.7% 발생: 손목 회전 시 그리퍼가 base/elbow.b에 충돌(self_clear -36.4)
    5D MLP 학습: 정확도 98.69%, 위험재현율 96.8%(임계0.5)
    - 안전임계 0.11 → 재현율 99.5%(미탐 39→6), 오경보 2.5%, 추론 0.7µs/질의
    - cspace-learned.png: J6별 패널 — 그리퍼 피치(J6↑)가 위험영역을 키우는 모습 시각화
    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
    [cspace_rand.csv]
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2026-06-13 data(cspace): 5D 랜덤 100k 재학습 — 잔존위험 개선
    40k→100k 샘플(J2~J6), 마진 30/15(콜드스타트 연동):
    - 정확도 98.97%, 안전임계 재현율 99.53%
    - 오경보율 2.6→1.9% 개선
    - 놓친 위험 최악 침투 16.9→10.4mm, 중앙값 2.7→1.9mm
    → 30mm 보정마진이 완전 흡수, 실물은 최악 미탐에서도 안전(데이터↑가 안전보증 강화)
    - 40k는 100k로 대체
    [cspace_rand.csv, cspace_rand_100k.csv]
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2026-06-13 data(active-loop): 실운용 능동학습 4라운드 — 자기개선 수렴
    시드2000(랜덤)→능동3라운드(불확실 1500씩), 총 6500라벨:
    - R1 91.99% → R2 93.99% → R3 97.58% → R4 97.49%(재현율 포화)
    - 정확도 97.51→99.08% 단조증가
    - 누적 위험률 15→35%(추가자세가 경계 집중 = 능동이 약점 정확히 타격)
    핵심: 5000라벨(데이터 5%)로 균일 100k 모델 재현율(97.5%) 도달
    → 능동학습이 라벨 효율을 입증, 실물 시뮬을 오라클로 한 진짜 자가학습 루프.
    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
    [history.csv, labeled.csv]
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2026-06-14 fix(ai_server): Whisper ffmpeg 심(sudo 없이) — imageio-ffmpeg 정적 바이너리
    EdgeXpert는 무인 sudo 불가 + ffmpeg 미설치 → imageio-ffmpeg(pip) 정적 바이너리를
    런타임에 'ffmpeg' 심링크로 PATH 등록. whisper 오디오 디코딩 해결.
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2026-06-14 fix(control): 3페이지 AI fetch URL 절대경로화({% url %})
    증상: 3페이지 "서버 연결 안 됨". 원인: 상대경로 'ai/health/'가 /control/ 페이지에서
    /control/ai/health/로 잘못 해석돼 404 (앱은 루트 마운트, 엔드포인트는 /ai/health/).
    수정: 다른 템플릿처럼 {% url 'armvision:ai_health/plan' %} 절대경로 사용.
    검증: Django shell에서 ai_client.health()=ready True warm.
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2026-06-14 feat(control): 음성 명령 버튼 + 웹캠 2개 + 3D 미러 표시 수정
    - 3D 미러 안뜸 수정: arm3d 뷰에 @xframe_options_sameorigin
    (Django 기본 X-Frame-Options:DENY가 same-origin iframe도 차단 → 해제)
    - 마이크 버튼(🎤): MediaRecorder 녹음→audio_b64→서버 Whisper STT→계획
    ai_plan 엔드포인트 audio_b64(base64) 입력 지원
    - 웹캠 좌/우 2개 배치(1페이지처럼 cam_left/right 스트림)
    [views.py]
2026-06-14 feat(control): 3페이지 재설계 — 50:50 좌채팅(마크다운)/우 로봇상태
    - 레이아웃 50:50: 좌=채팅(전체높이, 크게), 우=로봇 헬스체크
    - 우측 상단: 좌/우 웹캠 가로 꽉 차게, 하단: 로봇팔 3D가 남은 공간 가득(드래그 회전)
    - LLM 답변 마크다운 렌더(굵게·목록·코드)
    - 3D 검은화면 수정: arm3d enterEmbed에서 resize 재호출 + ResizeObserver
    (iframe 레이아웃 후 renderer 크기 0 문제 해결)
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2026-06-14 feat(control): 3D 미러 부드러운 이동 — 실물과 동기 램프
    이전: 실행 완료 후 목표각으로 즉시 스냅(갑자기 점프).
    - arm3d 미러: 명령각을 '목표'로 잡고 매 프레임 ~2°/40ms(≈50°/s, 실물과 동률)로 보간
    (mirrorTargets 600ms 갱신 + mirrorRamp 40ms 이동, 로드 시엔 즉시 스냅)
    - control 실행: 목표를 fetch 전에 localStorage 기록 → 미러가 실물과 동시에 램프 시작
    (실패 시 from으로 되돌림)
    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
2026-06-17 fix(calib): J4(ch3) 모터 교체 보정 — J1형 모터, 0°=2680 / 180°=540
    - _SERVO_CAL[3]: [690,2800] → [540,2680] (실측)
    - arm3d.html SERVO_CAL 동일 반영(3D 미러 일치)
    [views.py]
2026-06-17 fix(calib): J6(ch5) 보정 갱신 — 0°=2750 / 180°=560 실측
    - _SERVO_CAL[5]: [560,2700] → [560,2750]
    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
    [views.py]
2026-06-17 fix(3d-mirror): 서버 관절상태를 진실로 — localStorage 드리프트 버그 해결
    증상: 실물은 전 관절 90°인데 3페이지 3D 미러가 꺾여 표시.
    원인: 미러가 localStorage(옛 명령각)를 읽음. 보정용 raw 펄스 이동·수동 홈
    복귀를 미러가 알 수 없어 드리프트.
    해결:
    - views.py: _JOINT_STATE(J1~J6, 기본 90°) 서버 보유. exec_joint가 낙관적
    갱신(실패 시 되돌림)·램프 시작각도 서버 상태 사용(클라 from 무시).
    /arm/joints/(현재각 폴링)·/arm/home/(홈 90° 재설정) 추가.
    - arm3d.html: 미러가 /arm/joints/ 폴링(250ms)→부드러운 램프. 로드 시 90°
    시작 후 서버 자세로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
    [urls.py, views.py]
2026-06-18 fix(calib): J4(ch3) 모터 J4↔J5 교체 보정 — 0°=2720 / 180°=540
    - _SERVO_CAL[3]: [540,2680] → [540,2720] (교체된 모터 실측)
    - arm3d.html SERVO_CAL 동일 반영
    [views.py]
2026-06-18 fix(calib): J5(ch4) 모터 J4↔J5 교체 보정 — 0°=2750 / 180°=600
    - _SERVO_CAL[4]: [620,2750] → [600,2750] (교체된 모터 실측)
    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
    [views.py]
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2026-06-18 feat(grasp-P1): 파지 데이터셋 스윕 — J1~J6 무작위 → TCP포즈+충돌 CSV
    확정 TCP 기준으로 [J1..J6, tcp_xyz, app_xyz, floor/self_clear, collision]
    기록 → grasp_dataset.csv. 역질의(IK)·파지 학습 데이터.
    - 4p '파지 데이터셋(P1)' 카드 + sweepGrasp()
    - C-space와 동일 패턴(_collideOnce·_csDownload 재사용)이나 J1 포함(방위각)
    - 접근 ay로 수직/수평 파지 분류(Python)
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2026-06-18 assets: 그리퍼/링크 STL 추가 + 축보정 반영 assembly.json
    파지용 그리퍼·링크 부품(b,ee,f,f.1,g,r,w) 추가. 관절 회전축
    기울기·위치 보정 결과를 assembly.json에 저장(리깅 정확화).
    [b.stl, ee.stl, f.1.stl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]
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2026-06-18 fix(grasp-IK): 수직/수평 프리셋을 데이터 기반 스냅으로 — 고정 공식 오류 수정
    증상: 수평 잡기가 도달 어려움(299mm)인데 수동으론 가능. 원인: '수평→'
    프리셋이 고정 공식(베이스쪽 +Z)이라 실제 도달가능 수평방향(-Z 바깥)과
    정반대 → 45° 필터가 근처 143개 후보를 전부 제외.
    해결: snapApproach() — 그 위치 근처 도달가능한 가장 가까운 수직/수평
    샘플의 실제 자세로 목표 프레임을 스냅 후 solveIK. 위치·방향 무관 항상 일치.
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2026-06-19 fix(grasp-P4): 동기 보간 실행 — 검사한 경로와 실제 이동 일치(바닥충돌 실해결)
    증상: 경로계획 후에도 수직↔수평 전환 시 바닥충돌. 원인: pathClear는
    동시 직선보간을 검사하나 rampCtrl은 관절별 등속(비동기)이라 끝나는
    시점이 달라 검사와 다른 중간자세를 지남 → 바닥 침범.
    해결: IK 이동을 동기 보간 실행기(ikDrive)로 — 모든 관절 동시 출발·도착
    (최대 변화 관절에 속도 맞춤). 실제 경로=검사 경로 → 바닥회피 보장.
    _tgt=angle로 rampCtrl 무력화. 경유점(업라이트)도 동일 실행.
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2026-06-19 refactor(pages): 3/3 — 집기 티칭 제거 + 페이지번호 정리
    - teach.html 삭제, views.py teach_* 엔드포인트·영속 제거
    (이동 헬퍼 _move_joint_to/_grip_to/_move_pose는 집기 시퀀스용 보존)
    - 자연어 제어 제목 5페이지로, 연결 안내 메시지 3페이지(3D제어)로 수정
    페이지 재구성 완료: 1·카메라 2·캘리브 3·3D제어 4·3D시뮬레이터 5·자연어제어
    [views.py]
2026-06-19 fix(sim): 4페이지 로드 후 제어모드 자동 진입 — IK·파지 무반응 해결
    증상: 4페이지가 조립모드로 시작 → 리깅 비활성 → ikDrive가 m.angle
    설정해도 applyAngles가 반영 못함(제어모드에서만 작동). 수동 '제어'
    클릭해야 동작.
    원인: 기존 setTimeout 50ms 모드전환이 STL 비동기 로드 전에 실행돼 실패.
    해결: 모델 로드 완료 콜백에서 view=sim이면 setMode('ctrl') 호출
    (rebuild+buildCtrlJoints 정상 진입).
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2026-06-19 revert(gripper): 그리퍼 개폐(J7) 카드·JS 제거 — 결합 과정에서 설정 방향으로
    사용자 요청: 별도 그리퍼 카드 대신 3페이지 결합 과정에서 직접 설정.
    그리퍼 카드·setGripper·보정 JS 제거, seqStepDone은 실물 fetch만 유지.
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2026-06-19 fix(gripper): 그리퍼=슬라이드(평행이동)로 변경 — 평행 그리퍼 맞춤
    손가락이 회전이 아니라 슬라이드(parallel-jaw)임. grip 타입을 회전→
    축 방향 평행이동으로 수정.
    - applyAngles: grip은 m._base+axis*거리(mm) 평행이동(rev는 회전 유지)
    - rebuild: 슬라이드 기준점 _base 저장
    - toGrip: grip 전환 시 범위 -60~60mm·거리0, 기존 grip 자동 마이그레이션
    - 테스트 슬라이더 라벨 회전°/슬라이드mm, axInfo 슬라이드축 안내
    - gOpen/gClose는 슬라이드 거리(mm), setGripper가 보간
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2026-06-19 fix(gripper): 축기울기·축위치를 그리퍼(grip)에도 허용
    핸들러가 rev만 허용해 grip에서 무반응이던 문제. fix만 차단으로 변경.
    → 그리퍼 슬라이드축 방향(축기울기)·기준점(축위치) 조정 가능.
2026-06-19 fix(rig): 축기울기·축위치 드리프트 해결 — 조정 전 휴식자세 리셋
    증상: 축 조정·저장 시 위치/보정값이 계속 드리프트. 원인: rebuild가
    현재 슬라이드/회전 위치를 베이스에 구워서 누적.
    해결: _restFlatten()(전 관절 휴식자세 grip=0·rev=90 + 평면화)을 축기울기/
    축위치 전에 호출(editOffset과 동일 패턴). 조정 후 슬라이더도 갱신.
2026-06-19 fix(gripper): 저장 시 STL 밀림·개폐보정 유실 해결
    증상: 저장 누르면 그리퍼 STL이 밀리고, 열림/닫힘 보정이 안 됨.
    원인1: 저장/editOffset이 grip 휴식을 90으로(=슬라이드 90mm) 리셋.
    원인2: 저장 직렬화에 gOpen/gClose 누락.
    - 저장·editOffset 휴식 리셋: grip은 0(슬라이드0)으로
    - mates 직렬화에 gOpen/gClose 추가(로드는 saved.mates 직접 사용 → 복원됨)
2026-06-19 fix(gripper): 결합 모드 진입 시 손가락 튐 — 그리퍼 슬라이드0 리셋
    증상: 조립→결합 누르면 그리퍼 STL이 이동. 원인: setMode가 rebuild 전
    그리퍼의 stale 각도(슬라이드)를 0으로 안 맞춰 적용됨.
    해결: mate/ctrl 진입 시 grip 각도=0(휴식), mate는 rev=90도 리셋 후 rebuild.
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2026-06-19 fix(grasp): 동기 평가 루프 손가락 stale 월드행렬 — rigRoot 강제갱신
    증상: 파지 학습 데이터 성공 0.5%, perp~227mm(손가락이 쉼 자세에 고정).
    원인: applyAngles는 로컬 변환만 갱신, 월드행렬은 다음 렌더에서 갱신.
    데이터생성/최적탐색/롤정렬 같은 동기 루프엔 렌더가 없어 손가락 월드가
    직전 렌더(쉼자세)에 고정 → 쉼자세 근처 물체만 성공.
    해결: _graspQuality·_closingPerp·evalGraspContact에서 applyAngles 후
    rigRoot.updateMatrixWorld(true)로 체인 월드행렬 강제 갱신.
2026-06-20 feat(grasp-learn): 데이터 균형 — 음성(못 잡는 경우) 샘플 추가
    수정 후 성공률 99%(도달영역만 샘플)라 학습에 음성 부족. C-space가
    안전/위험 둘 다 학습했듯 파지도 경계 학습 필요.
    - 60% 도달영역 근처(DB tcp + 지터±35) = 양성+경계
    - 40% 워크스페이스 전역(DB tcp 바운딩박스+여유 40mm) = 음성+경계
    → 도달/미도달·파지가능/불가 균형 잡힌 라벨.
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2026-06-20 fix(grasp-learn): 그리퍼 벌림 물리제약 — 큰 물체 못 잡음 반영
    증상(50k 실험): 반경 클수록 성공률↑(R150+=99%) — 그리퍼가 못 잡는
    큰 물체가 성공으로 라벨. 원인: ① 벌림 제약 없음 ② 정렬 임계 perp<R*0.6가
    크기 비례라 큰 물체에 관대.
    수정: 그리퍼벌림(glGrip, 기본 80mm) 입력 추가 → 2R>벌림이면 자동 실패
    (검색 생략). 정렬 임계를 고정 12mm로(크기 비례 제거). 기본 반경 8~40mm
    (그리퍼 스케일), 높이 10~120mm.
2026-06-20 fix(grasp-learn): 그리퍼 벌림 실측 50mm 반영(반경≤25 잡힘)
    실측: 그리퍼 최대 지름 50mm. 기본 그리퍼벌림 50, 반경 5~35mm
    (잡힘 ≤25 + 경계 음성 25~35)로 조정.
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2026-06-20 feat(grasp-learn): 바닥에 놓인 물체 샘플링 — 형상(납작→수직) 효과 반영
    데이터 확인: 바닥(floor_clear<20)은 tcp_y≈0·16, 수평 grasp 평균
    tcp_y=287 > 수직 158 → 낮은 곳은 수평이 바닥충돌로 불가. 기존엔 물체
    y를 H와 무관히 뽑아 형상효과 묻힘.
    수정: 물체 중심 y = 바닥y + H/2 (바닥에 놓임). x,z만 워크스페이스에서
    샘플. 납작=낮음→수평 바닥충돌→수직만, 키큰=높음→수평 가능. 바닥높이
    입력(glFloor, 기본 0) 추가.
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2026-06-20 feat(grasp): 물체-팔 충돌 검사 + 단일물체 최적자세 찾기 + MLP early stop
    핵심 누락 수정: 파지 유효성에 '물체-그리퍼 몸체 충돌' 검사 추가
    (_gripperHitsObject: 손가락 제외 그리퍼 부품이 물체에 3mm↑ 침투=충돌).
    지금까지 DB는 바닥·자기충돌만 봐서 몸체가 물체를 파고드는 자세도 통과했음.
    🎯 최적 자세 찾기(voOpt): 물체 고정, 근처 자세 전수 평가(jaw 쏙+충돌없음+
    깊이) → 손목 정밀화 → 최적 실행. 충돌없는 자세 우선(패널티 500).
    MLP early stopping: 검증 8 epoch 정체 시 중단(과적합 방지).
    [views.py]
2026-06-20 fix(grasp-learn): 데이터 생성을 충돌 인식으로 — 학습 데이터 미완성 해결
    진단(사용자): grasp_dataset/grasp_learn이 물체-팔 충돌을 무시해 몸체가
    물체를 파고드는 자세도 '성공'으로 학습됨.
    해결: 그리퍼 몸체(손가락 제외)를 TCP-로컬로 1회 사전계산(_precomputeGripperBody)
    → _bodyHitsObject로 관절 재적용 없이 빠르게 충돌검사. _searchObjGrasp 빠른경로가
    jaw 유효 후보를 품질순 정렬 후 '충돌없는 최선'을 반환. 데이터 생성 success에
    !collide 추가 → 충돌없는 자세만 성공으로 라벨 → 모델이 깔끔한 파지 학습.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
2026-06-20 fix(grasp): 두 단계 직선경로 막히면 직접접근 폴백 + 접근맵 CSV 저장
    문제: P2(이 위치 잡기)는 경유점 우회로 되는데, 두 단계는 프리→그래스프
    직선구간이 바닥/자기충돌이면 우회 불가로 '충돌없는 경로 없음' 중단.
    수정: pathClear(pre,G) 검사 후 막히면 원본 G로 executeGrasp 직접 폴백
    (P2처럼)→ 항상 잡음. 검사 후 현재자세 복원.
    접근맵: 격자 결과를 approach_map.csv(obj_x,z,R,H,vert_ok,vert_tilt,
    horz_ok,horz_tilt)로 완료 시 저장.
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2026-06-20 fix(grasp): 직접접근 폴백이 닫기·부착 안 하던 버그
    증상: AI 파지/🎯가 물체까지 가나 그리퍼 안 닫힘, '여기 놓기'는 든 물체
    없음. 원인: 직선경로 막힐 때 폴백이 executeGrasp(이동만)이라 닫기·부착
    누락. 수정: _directGrasp(G로 이동+grip:'close' 1스텝)→ seqStepDone에서
    setGripper(닫기)+_attachObj(부착) 실행. 두 폴백 모두 교체.
2026-06-20 fix(place): 들어올림→운반→하강 + 놓기 Y 입력 + IK목표 물체 추적
    문제: ① 물체 이동해도 IK 목표 좌표 안 따라옴 ② 놓기 좌표 xz만이라 Y 공중
    ③ 운반 중 바닥 쓸기.
    - _updateHeld가 ikX/Y/Z를 든 물체 위치로 갱신 → 마커가 물체 따라감
    - 놓기 Y 입력(plY, 물체 중심 높이) 추가
    - executePlace: 들어올림(현재·목표 중 높은 곳+90mm)→운반(목표 위)→하강→
    release→후퇴 4단계로 바닥 쓸기 방지
    - _directGrasp(폴백)도 닫기 후 들기 추가
    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
2026-06-20 fix(stereo3d): _T 미로딩 센티넬을 'unset' 문자열→고유객체(is 비교)
    _T가 한 번 로드돼 ndarray가 되면 `_T == "unset"` 비교가 배열을 반환,
    if문에서 "truth value ambiguous" ValueError로 /positions3d/ 500.
    _UNSET=object() 센티넬 + is 비교로 해결.
    [stereo3d.py]
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2026-06-20 feat(grasp/place): 자이로 대칭 뒤집기 강화 + 접근 중 자이로 유지
    평행집게는 접근축(z) 180° 회전에 같은 파지 → J6가 0~180° 한계에 걸리면
    면을 뒤집어 범위 안에서 수평 유지.
    - _flipQ/_bestPlaceQ: q와 flip(q) 중 목적지에서 J6 범위 내로 더 잘 닿는
    자세 자동 선택(위치 우선+자세).
    - executePlace: wpC(목적지) 기준 대칭 자세 선택 후 운반 내내 동일 자세.
    - executeGraspTwoStage: 이상자세도 대칭 후보 평가, standoff·들기 IK에
    ow=4 적용 → 물체 잡으러 갈 때도 자세(수평) 유지. 도달 게이트를
    pre.err>80 → pre.posErr>45(ow 무관)로 변경.
    - _placeReach(놓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
2026-06-20 fix(place): 마커-실행 도달판정 불일치 해소 + 운반높이 적응
    마커는 wpC로 직접 IK(27mm 가능)인데 실행은 들어올림→운반(높은 지점)→하강
    체인이라, 먼 저점 목적지는 운반지점(+90mm)이 도달 불가→체인 붕괴(238mm).
    - _planPlace(): 마커·실행 공용 경로 계획. 자이로 레벨링+대칭 자세 선택 후
    운반높이를 90→60→40→20→0 적응적으로 낮춰 도달되는 계획 채택.
    - executePlace/_placeReach 모두 _planPlace 사용 → 마커 초록=실행 성공 일치.
    - 운반높이 낮춰 진행 시 상태에 표시.
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2026-06-21 feat(calib): 관절 보정 실제 스윕 구동 — 안전 박스 내 자동 이동 + 마커 수집
    - joint_cal.transition_order: cur→tgt를 단일관절 이동 순서로(모든 중간 full-config
    is_safe인 순서만, 없으면 skip). 단일관절 이동은 양 끝 안전→경로 전체 안전(구간).
    SAFE_HOME 추가.
    - views: 백그라운드 _sweep_worker(안전박스 자세 한 관절씩 이동→정착→마커 measure
    →팔 마커 id0~7 수집→joint_sweep.json 저장). joint_sweep_start(연결+시작자세
    박스-내 가드, 밖이면 need_park 거부)/status/stop.
    - 6단계 UI: ▶ 실제 스윕 실행 + 중지 + 진행바·상태 폴링, 안전 경고.
    - 검증: django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
    [joint_cal.py, urls.py, views.py]
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2026-06-21 feat(calib): 관절 보정 스윕 데이터 시각화 — joint_sweep_analysis.py
    joint_sweep.json → 2개 3D 그림:
    (a) 팔 마커(id0~7) envelope: 스윕 동안 각 링크 마커 자취(로봇기준).
    (b) 말단(id7)을 명령 J2로 색칠: 어깨각별 말단 분포(중력 sag 진단 토대).
    60자세 데이터 확인(마커 53~60회 검출). docs/image/joint_sweep.png 저장.
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2026-06-21 fix(calib): k 추출 부호(|k|)·필터 break 버그 수정
    - fit_circle_3d 법선 부호 임의 → 음수 k(J1 -0.56·J3 -0.95) 발생 → abs(k)로.
    - 마커 필터 실패 시 break(다음 마커 미시도) → 통과 시에만 break, 실패 시 더
    proximal 마커 시도. 부분스윕별 k(자세 의존) 출력.
2026-06-21 feat(calib): 관절 보정 적용 — servo_corr.json + 명령 시 펄스 보정(토글)
    - joint_correct.py: 추출한 k를 servo_corr.json {Jk:{ch,k,ref}} 저장
    (J1 0.59·J2 0.72·J3 0.95·J4 0.93).
    - views: _ang_to_us에 보정 적용 — ARM_CFG.correct ON이면 θ_cmd=ref+(θ−ref)/k.
    nominal _SERVO_CAL 유지(이중값). /arm/config/로 토글, corr_joints 노출.
    측정 스윕은 보정 OFF 강제(순환 방지)+원복.
    - 6단계 UI: '보정 적용 ON/OFF' 토글(검증용 A/B).
    - 검증: OFF J2 70°=1838µs → ON 1930µs(명령 62.2°분), 기준 90° 불변.
    다음: 보정 ON 후 실측 검증(특히 J1 0.59), 필요시 J2 자세의존(B)·offset.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
    [servo_corr.json]
2026-06-21 fix(stereo3d): calib/T 파일 변경 시 자동 재로딩 — 작업공간 재보정 즉시 반영
    stereo3d가 calib/T를 모듈 캐시 → reload() 호출 타이밍에 따라 옛 데이터(과거
    보정) 사용 가능. _load/_load_T가 파일 mtime을 추적해 바뀌면 자동 재로딩.
    이제 1페이지 3D가 항상 최신 작업공간 보정/앵커 T를 사용. reload()도 유지.
    [stereo3d.py]
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2026-06-21 fix(ai): pick/place 실패 시 실제 이유(ikStat)를 로그에 표시
    executeDSL이 _waitSeq 실패 시 ikStat 내용(도달 불가/충돌경로 등)을 aiLog에
    캡처 → 왜 실패했는지 진단 가능.
2026-06-21 fix(ai): Gemma DSL JSON 잘림 방지·복구 — reasoning이 길어 토큰한계서 끊김
    "물병을 왼쪽으로" 명령에서 reasoning이 512토큰 초과로 잘려 JSON 미종료 파싱실패.
    - server.handle_command: actions 먼저+reasoning 짧게(마지막) 프롬프트, max_new
    512→1024.
    - dsl.extract_json: 파싱 실패 시 _salvage_actions로 actions 배열만 복구(문자열/
    대괄호 균형 추적, 끝 잘리면 마지막 완전 }까지). 자가테스트 OK.
    EdgeXpert 배포·재시작.
2026-06-21 fix(grasp): _ikGraspPose 실패 이유 구분(도달 불가 vs 충돌) 표시
    aiGrasp 실패 시 'IK 실패'만 떠 원인 불명 → _ikGraspPose가 {ok,reason,j} 반환:
    도달 불가(IK 위치오차 Xmm>30)인지, 충돌(그리퍼/팔 간섭)인지 메시지로 구분.
2026-06-21 fix(grasp): _ikGraspPose 다중 시작자세 IK — 국소최소로 도달 가능한데 실패하던 것 해결
    DB-free 전환 후 현재자세(cur) 하나에서만 국소 IK → 목표가 멀면 국소최소에
    빠져 닿을 수 있는 곳도 '도달 불가'. J1 방위각 5개+현재자세로 다중 시드 시도해
    최적 채택. (예전 DB가 주던 좋은 시드를 대체)
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2026-06-21 fix(orchestrator): set_joint 각도 미지정→역질문 + joint 소문자 정규화
    - 'J1 움직여줘'(각도 없음) → angle 환각 금지, ask_user '몇 도로?'
    - Gemma가 'j1' 소문자 출력해도 validate_dsl이 'J1'로 정규화(노트북 대문자 필요)
2026-06-21 fix(6p): set_joint joint 대문자 정규화(방어적, j1→J1)
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2026-06-21 fix(grasp): 좌표 지정 파지는 MLP 품질 veto 건너뛰기
    - aiGrasp(opts.skipVeto): 좌표 직접지정(pick at)·📍 버튼은 MLP 품질
    veto를 무시하고 실제 IK(_ikGraspPose 도달·충돌)가 판정
    - 이유: MLP(~85% 근사)가 false-negative로 잡을 수 있는 위치를 막음
    (4페이지 grasp_dataset 검색은 잘 잡힘 = 그 위치 파지가능 증명)
    - 비전 기반 🧠 AI 파지는 veto 유지(불확실성 차단)
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2026-06-21 fix(grasp): grasp_dataset 업로드 0바이트 저장 버그
    원인: CSV가 2.5MB(DATA_UPLOAD_MAX_MEMORY_SIZE 기본) 초과 → request.body
    접근 시 RequestDataTooBig 예외. open(wb)가 먼저 파일을 비운 뒤라 0바이트만 남음.
    - settings: DATA_UPLOAD_MAX_MEMORY_SIZE 200MB로 상향
    - view: body를 open 전에 읽고 빈 본문이면 기존 파일 보존
    [views.py]
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2026-06-21 fix(6p): 제자리 내려놓기 = 그리퍼 열기(경로계획 제거)
    문제: '그냥 놔'(좌표없는 place)도 executePlace의 _findPlaceSpot 경로계획을
    돌려서 '놓을 지점 없음'으로 실패. 들고 있는 그 자리인데도.
    - _releaseInPlace(): 경로계획 없이 그 자리에서 J7 그리퍼 열고(시뮬+실물)
    든 물체를 그 XZ 바닥으로 떨어뜨림 → 항상 성공
    - executeDSL place: 좌표/타겟 없으면 executePlace 대신 _releaseInPlace
    - 좌표·타겟 지정 place는 기존대로 executePlace(경로계획)
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
